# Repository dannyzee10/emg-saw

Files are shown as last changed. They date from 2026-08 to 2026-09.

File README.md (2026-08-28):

# EMG-SAW — Beihang EMG Acquisition System + GUI

An open, low-cost, **5-channel dry-electrode surface-EMG** acquisition system with a
real-time, research-grade GUI — a self-owned alternative to Noraxon MR / Delsys Trigno.
Built and run as a **SAFe Agentic Workflow (SAW)**: 6 specialist agents, a code
knowledge-graph, and an agent "world-map".

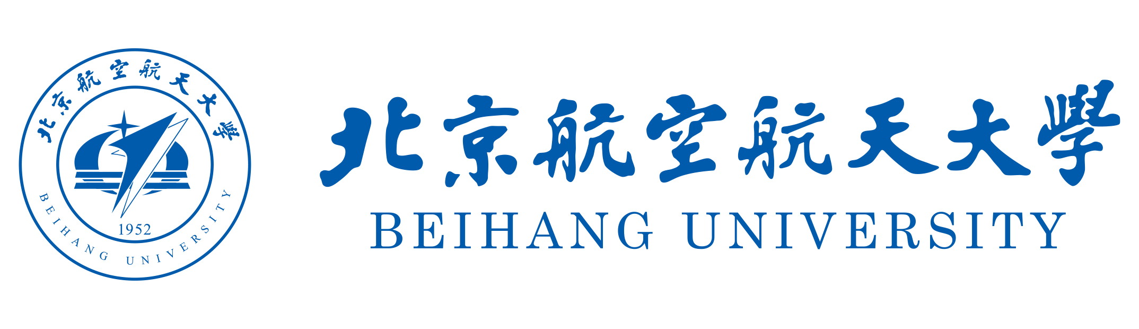
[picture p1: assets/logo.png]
Beihang University


## Quick start
```bash
python -m venv venv
# Windows:  .\venv\Scripts\activate      # macOS/Linux:  source venv/bin/activate
pip install -r requirements.txt

# see the full UI with no hardware:
python emgscope.py --sim --channels 5

# real hardware (STM32 flashed with CP4 firmware, CP2102 on COMx):
python emgscope.py --port COM8 --baud 921600 --channels 1 --fs 2000 --coupling AC --kick
```

## What it does
Real-time multi-channel scope (sweep/scroll, DC/AC/GND coupling, V/div, Time/div) with
per-channel **RMS, pk-pk, median frequency (fatigue), activation meter**, **MVC % normalization**,
**onset highlight**, **live FFT spectrum**, event markers, snapshot, and one-click HTML reports.
Firmware: STM32F103 timer-paced ADC + DMA ping-pong streaming binary frames @ 2 kHz.

## Architecture
```
skin → dry electrodes → analog front-end → STM32 ADC (TIM+DMA) → binary/UART → PC GUI (PyQt5/pyqtgraph)
```

## Repo
- `emgscope.py` — launch the scope · `gui/` (MVC) · `dsp/` · `communication/` · `firmware/`
- `scripts/` — `flash_run.bat`, `refresh.ps1`, `agent_map.py` (world-map)
- **New here? Read [`HANDOFF.md`](HANDOFF.md) first** — complete context, run guide, and roadmap.
- Facts: [`PROJECT_CONTEXT.md`](PROJECT_CONTEXT.md) · Gates: [`QUALITY_BAR.md`](QUALITY_BAR.md) ·
  Roadmap: [`docs/EMG_SAW_Retro_and_Competitive_Roadmap.md`](docs/EMG_SAW_Retro_and_Competitive_Roadmap.md)

## Status
CP1–CP4 complete (2 kHz binary pipeline, full instrument). Next: 5 channels, then ADS1299 24-bit
front-end, wireless, IMU. See `HANDOFF.md` §6–7.

_Owner: Muhammad Daniyal · MS Biomedical Engineering · Beihang University._

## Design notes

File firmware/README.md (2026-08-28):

# EMG Firmware

## Status
Skeleton only. Not yet complete.

## Build Tools
- STM32CubeMX + Keil/IAR/SW4STM32
  or
- PlatformIO (with stm32duino or HAL)

## Configuration
- MCU: STM32F103C8T6 (Blue Pill)
- Clock: 72 MHz (from 8 MHz HSE via PLL)
- ADC: ADC1, 12-bit, 8 channels, DMA circular
- Timer: TIM2, update event @ 2 kHz (period = 72MHz/(2kHz) = 36000, PSC = 0)
- UART: USART1, 921600 baud

## Protocol
- Version: 2
- Frame: 0xAA 0x56 | seq(2) | data(8*2) | crc(2)
- CRC: CRC-16/CCITT-FALSE (poly 0x1021, init 0xFFFF) over seq+data

## TODO
- [ ] Complete HAL initialization code
- [ ] Verify DMA circular buffer size and interrupt priorities
- [ ] Test with PC-side round-trip test
- [ ] Implement hardware flow control if needed

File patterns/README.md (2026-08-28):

# Patterns

> **Note**: This repository already has a `patterns_library/` directory with 11 production patterns.
> This `patterns/` directory is reserved for whitepaper-specific pattern documentation.

## Existing Patterns

See [`../patterns_library/`](../patterns_library/) for:

- 11 production-tested patterns (API, Database, UI)
- Pattern discovery protocol
- Security validation checklists

## Whitepaper Patterns (Coming in v1.1)

Additional patterns documented in the whitepaper will be added here:

- Case study patterns (PGM-321, PGM-323)
- Meta-circular validation patterns
- Evidence-based delivery patterns

## Current Status

For now, see:

- [Existing Pattern Library](../patterns_library/README.md) - 11 production patterns

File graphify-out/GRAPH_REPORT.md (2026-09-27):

# Graph Report - pcb-routing-0925  (2026-09-27)

## Corpus Check
- 942 files · ~5,435,691 words
- Verdict: corpus is large enough that graph structure adds value.

## Summary
- 6135 nodes · 11253 edges · 675 communities (364 shown, 133 thin omitted)
- Extraction: 99% EXTRACTED · 1% INFERRED · 0% AMBIGUOUS · INFERRED: 111 edges (avg confidence: 0.86)
- Token cost: 0 input · 0 output

## Graph Freshness
- Built from commit: `39b95e40`
- Run `git rev-parse HEAD` and compare to check if the graph is stale.
- Run `graphify update .` after code changes (no API cost).

## Community Hubs (Navigation)
- EmgScope
- EMG Bring-up Checkpoint Log
- ReviewWindow
- emg_plotter.py
- graphify query
- emg_bluepill/main.c
- afx_124242.pas
- Beihang University Logo (logo.png)
- graphify clone (GitHub)
- Patterns Library (11 production patterns)
- Token reduction benchmark
- FalkorDB export
- GraphML export
- Neo4j export
- SVG export
- Wiki export
- MVC Normalization (% MVC)
- MetricsCalculator
- Hard gate rules
- EMG SAW — HANDOFF (read this first)
- agent_map.py
- pre-commit
- DSP Engineer Playbook
- Firmware Engineer Playbook
- GUI Engineer Playbook
- Hardware Engineer Playbook
- Test Engineer Playbook
- Systems Architect Playbook (Brain Agent)
- EMG UART Protocol Specification
- Sequence Number Width Evaluation
- EMG Firmware
- src/main.c
- FrameParser
- GUI Architecture Proposal (EMG Instrument)
- EmgPlotWidget
- RecordingController
- test_dsp_analytics.py
- MvcDialog
- Cited Findings
- s3_000002.pas
- AmpNormDialog
- ar2_113622.pas
- Tomorrow — Live PA0 EMG data check (CP5 "signal sanity")
- Cited Findings
- svc_swap3_T.pas
- sc_234902.pas
- a6a_133022.pas
- apq_123711.pas
- svc_swap2_T.pas
- Handler
- sx_233624.pas
- router4.py
- compact_mainboard_20260925T115919Z/work/router5.py
- Lead-off calibration & validation — 2026-08-29
- Launcher
- launchers.md
- Data Pipeline — 5-Channel Simultaneous EMG Streaming (feasibility + optimal design)
- Complete Pin-by-Pin Connection Reference — AS BUILT
- 5-Channel Wireless Wearable EMG Board — Project Handoff
- PROJECT_CONTEXT.md
- Main Board — PCB Layout Rules (floorplan, stack-up, keep-outs, guard, vias)
- Main Board — Power Tree, Schematic-Level Design
- Main Board — 5-Channel Schematic (net-by-net) + BOM
- AFE Signal Chain — confirmed topology + values + 5-channel integration
- QUALITY_BAR.md
- EMG SAW — Retrospective + Competitive Roadmap
- EMG-SAW — Beihang EMG Acquisition System + GUI
- pcb_layout_2026-09-24_routing/work/router5.py
- Analog front-end PCB layout and routing requirements: AD8237 / MCP6404 / MCP6401 / VREF distribution / ADC-input RC / Hirose BK13C (5-ch sEMG main board)
- Fabrication & stack-up limits for the 4-layer JLCPCB EMG main board (80 × 45 mm, FR-4, ENIG, through vias)
- STM32U575VIT6 (LQFP100, non-SMPS): ST layout and routing requirements for U_MCU1 on the EMG main board
- ST67W611M1A6BTR (integrated PCB antenna) on the EMG main board: manufacturer layout requirements for the antenna, grounding, decoupling, 32.768 kHz crystal and SPI host interface
- grid_router.py
- router3.py
- EMG main-board PCB implementation brief — Astra
- compact_mainboard_20260925T115919Z/work/geom.py
- pcb_layout_2026-09-24_routing/work/geom.py
- compact_mainboard_20260925T115919Z/work/apply_ops_v6.pas
- tn_215701.pas
- tr_215530.pas
- ap_171624.pas
- pcb_layout_2026-09-24_routing/work/apply_ops_v6.pas
- aB_213758.pas
- apply_B.pas
- dB_212322.pas
- dC_213555.pas
- fx_214355.pas
- ab2_201729.pas
- ab3_203355.pas
- apply_ops_b2.pas
- apply_ops_b3.pas
- apply_ops_b4.pas
- apply_ops_b5.pas
- apply_ops.pas
- dA_212014.pas
- apply_ops_b1.pas
- EMG main-board placement checkpoint — 24 September 2026
- Unbroken Planes and Tight Loops Govern Routing
- Compact two-sided main board — change audit (R2)
- plan_gnd_fanout2.py
- Remote battery NTC assembly — PROTO_1_REMOTE_NTC
- plan_gnd_fanout.py
- api_test.pas
- at_210845.pas
- Next-agent checkpoint — compact main board (R2)
- apply_fp.pas
- fpB_214118.pas
- fpd_214035.pas
- gen_evidence.py
- compact_mainboard_20260925T115919Z/work/export_geometry.pas
- flip_test.pas
- ft_210529.pas
- gen_B_ops.py
- ot_211603.pas
- outline_test.pas
- Opus continuation changelog — routing revision
- pcb_layout_2026-09-24_routing/work/export_geometry.pas
- plan_bk13_escape.py
- classify_copper.py
- plan_B.py
- compact_mainboard_20260925T115919Z/work/render_area.py
- render_compare.py
- partial_status.py
- peak_mem.py
- probe_board.pas
- pcb_layout_2026-09-24_routing/work/render_area.py
- save_board.pas
- to_local
- compact_mainboard_20260925T115919Z/work/audit_plan.py
- compact_mainboard_20260925T115919Z/work/build_ops.py
- compare_pads.py
- h
- export_baseline.pas
- repair_guided_fix.py
- flip_probe2.pas
- fp_210726.pas
- router_command
- xb_205224.pas
- pcb_layout_2026-09-24_routing/work/audit_plan.py
- pcb_layout_2026-09-24_routing/work/build_ops.py
- probe_bodies.pas
- probe_free_bodies.pas
- replan_pads.py
- route_quality.py
- split_plan.py
- analyze_baseline.py
- analyze_flip.py
- compare_readback.py
- list_sheet.py
- make_trial_ops.py
- compact_mainboard_20260925T115919Z/work/parse_drc.py
- render_placement.py
- repoint_prjpcb.py
- setup_kit.py
- summarize_bodies.py
- build_batch2.py
- build_rule_ops.py
- clean_partial.py
- make_router5.py
- make_writer_test.py
- pcb_layout_2026-09-24_routing/work/parse_drc.py
- render_plan.py
- render_zoom.py
- sy_234341.pas
- dsp.py
- EmgFilters
- ac_235440.pas
- ad_235603.pas
- af_001001.pas
- ag_001433.pas
- apply_C2_T.pas
- as_000004.pas
- plan_C2.py
- ape_052111.pas
- router_command
- routed_plans
- c2lib.py
- emg_features.py
- c2audit.py
- ae_101824.pas
- Compact candidate C2 — change audit (26 Sep 2026)
- find_spot
- place
- export_geometry_T.pas
- gw_001620.pas
- gx_235734.pas
- gy_000106.pas
- gz_001139.pas
- la_233408.pas
- probe_libadd_T.pas
- render_c2_native.py
- lr_233251.pas
- exists
- probe_libread_T.pas
- exists
- routed_plans
- preserved
- export_bodies_T.pas
- make_apply_c2.py
- make_svc_swap3.py
- pr_235306.pas
- probe_pasterule_T.pas
- variant_svc_T.pas
- vs_001533.pas
- vt_001542.pas
- drc_details.py
- gen_c2_svc_ops.py
- make_c2_templates.py
- mkrun.py
- mkvariant.py
- render_service_map.py
- apply_ops_T.pas
- at_105742.pas
- ho_103856.pas
- tc_110641.pas
- tk_110924.pas
- tq_111343.pas
- tr_110331.pas
- tu_111542.pas
- p6c_123528.pas
- gr3_113947.pas
- compare_drc_rounds.py
- g2_by_connection.py
- gd_110815.pas
- ge_111110.pas
- gf_111511.pas
- gh_104401.pas
- gr_111721.pas
- gt_105859.pas
- prune_from_antennae.py
- find_dangling.py
- patch_tools_c2.py
- filter_trial_plan.py
- gen_c2_escape_rules.py
- gen_trial_cleanup_ops.py
- make_c2_round_input.py
- make_c2_trial_input.py
- make_ops_template.py
- plan_to_ops.py
- trial_failures.py
- trial_summary.py
- p6p_123322.pas
- a6o_213811.pas
- a6b_155432.pas
- stitch.py
- a6c_163445.pas
- s6c_123459.pas
- s6d_120322.pas
- s6e_121023.pas
- s6f_122250.pas
- s6g_123036.pas
- stack6_T.pas
- plan_bk13_escape_c2.py
- g6_123554.pas
- g6a_133240.pas
- dru_123247.pas
- dump_rules_T.pas
- rip_conflicts.py
- make_router_input_6l.py
- nudge_stitch.py
- unrouted_summary.py
- ddl_155255.pas
- kop_154628.pas
- p6c2_155904.pas
- p6e_163638.pas
- md2_155729.pas
- mdl_155321.pas
- gaf_052111.pas
- a6g_171008.pas
- relocate_drl.py
- g6b_155350.pas
- g6c_155819.pas
- g6d_155951.pas
- g6e_163611.pas
- g6f_163746.pas
- render_bk13_band.py
- a6h_181848.pas
- a6j_190538.pas
- a6m_193630.pas
- p6h_182535.pas
- p6k_191112.pas
- rgp_194117.pas
- rin_190641.pas
- apr_202815.pas
- C2 6-layer routing completion — resume note (keep this file current)
- g6g_171149.pas
- g6h_182354.pas
- g6i_182649.pas
- g6j_190611.pas
- g6k_191049.pas
- g6l_191206.pas
- g6m2_194006.pas
- g6m_193659.pas
- ggp_195007.pas
- diag_route.py
- mcu_through_traffic.py
- render_routed.py
- rip_blockers.py
- rip_region.py
- apply_rip_offline.py
- repair.py
- a6p_220109.pas
- g6n_202946.pas
- a6q_221928.pas
- mch_220109.pas
- a6s_232727.pas
- a6r_225457.pas
- place_part.py
- g6o_214442.pas
- g6p_220109.pas
- g6q_221928.pas
- render_parts.py
- a6t_001212.pas
- g6r_225457.pas
- ConsistentRepairTests
- a6u_004421.pas
- g6s_232727.pas
- g6t_001212.pas
- a6v_012437.pas
- g6u_004421.pas
- apx_033252.pas
- g6v_012438.pas
- prx_033722.pas
- pry_033832.pas
- rrg_024216.pas
- mrg_024217.pas
- apa_040850.pas
- g6w_024217.pas
- g6x_033252.pas
- g6y_033722.pas
- g6z_033832.pas
- render_window.py
- apc_044145.pas
- pra_041418.pas
- aph_063917.pas
- gaa_040850.pas
- gab_041418.pas
- gac_044145.pas
- plane_route.py
- run_repair.py
- rpg_055739.pas
- mvg_055739.pas
- asw_124433.pas
- mcb_123711.pas
- gloss.py
- gag_055739.pas
- gah_063917.pas
- rip_attached.py
- api_073926.pas
- apn_105426.pas
- rtp_095144.pas
- gai_073926.pas
- apj_083031.pas
- apl_094611.pas
- prj_083356.pas
- gaj_083031.pas
- gak_083357.pas
- gal_094611.pas
- mtp_095144.pas
- gam_095144.pas
- gan_105426.pas
- gao_123712.pas
- gap_124242.pas
- gaq_124433.pas
- fab_check.py
- aup_135846.pas
- rcb_135636.pas
- rrn_125439.pas
- apw_151610.pas
- mcbt_135637.pas
- mr2_125917.pas
- mrn_125439.pas
- gav_151610.pas
- ProcessingDialog
- msk_161919.pas
- gar_125439.pas
- gas_125917.pas
- gat_135637.pas
- gau_135846.pas
- pinswap_T.pas
- psw_161601.pas
- psw_161614.pas
- gaw_161651.pas
- gax_161919.pas
- sch_dump_T.pas
- sdm_155058.pas
- apu_163913.pas
- apz_173925.pas
- Handoff to Astra — C2 6-layer EMG main board: finish the routing (27 Sep 2026, 21:xx)
- uartswap_T.pas
- router_command
- gaz_173925.pas
- merge_rounds.py
- prune_chain.py
- gay_163913.pas
- sdm2_162742.pas
- neg_sweep.py
- astra_verify_routing_delta.py
- .check
- astra_verify_via_rule_delta.py
- astra_apba_185646.pas
- astra_apbb_191935.pas
- astra_apbc_200754.pas
- astra_apbd_202424.pas
- astra_apbe_204152.pas
- astra_apbe_ready_205633.pas
- astra_apbf_final_211832.pas
- astra_apbf_ready_211056.pas
- astra_apbg_220654.pas
- astra_apbg_final_222332.pas
- astra_apbg_rebased_223912.pas
- astra_apbh_225024.pas
- astra_apbh_centered_225113.pas
- astra_apbj_230930.pas
- drc
- GlossContactTests
- astra_audit_trace_rules.py
- NativeTraceRuleTests
- inventory
- explicit_seed
- ASTRA_BF_CS_BOTTOM_PLANNING_ONLY/MANIFEST.json
- ASTRA_BF_CS_SEEDED_PLANNING_ONLY/MANIFEST.json
- ASTRA_BF_TX_SEEDED_PLANNING_ONLY/MANIFEST.json
- astra_verify_pcb_structure.py
- ASTRA_CH4_LOCAL2_PLANNING_ONLY/MANIFEST.json
- astra_align_via_rule_T.pas
- astra_viabi_225318.pas
- All free trace audit and via evidence — 2026-09-27
- Channel 4 routing correction — native checkpoint BC
- Routing completion and all-trace check — BJ, 27 September 2026
- SeedPlansTests
- BF testpad relocation and MCU92 escape: planning evidence
- All-trace verification coverage review
- Gloss contact guard: code and synthetic test evidence, 27 September 2026
- Guided partial-rip corridor and seed plan inputs, 27 September 2026
- MCU UART RX routed — native checkpoint BF
- Radio UART RX routed — native checkpoint BE
- Vc_1 native routing checkpoint BD — 27 September 2026
- astra_gaz_185646.pas
- astra_gba_185646.pas
- astra_gbb_191935.pas
- astra_gbc_200755.pas
- astra_gbd_202424.pas
- astra_gbe_204152.pas
- astra_gbf_210912.pas
- astra_gbfs_223242.pas
- astra_gbg_220655.pas
- astra_gbgm_224135.pas
- astra_gbh_225024.pas
- astra_gbi_225714.pas
- astra_gbj_230930.pas
- astra_move_cl4_T.pas
- astra_mvcl4_200754.pas
- astra_tp_gnd_dig_move_scan.py
- astra_unsavedbf_222959.pas
- Combined bounded cleanup of all ten BH antenna warnings
- astra_ch4_trial.py
- astra_check_mcu_rx_power_graph.py
- astra_check_mcu_rx_reinforced_graph.py
- astra_check_uart_partial_graph.py
- astra_check_uart_rx1_graph.py
- astra_cl4_feasibility.py
- astra_cs_tx_local_detour.py
- astra_finalize_bj.py
- astra_mcu92_inward_seed_check.py
- astra_move_gnd_tp_T.pas
- astra_mvbgm_224135.pas
- MCU_WIFI_UART_RX candidate review
- Two remaining BF opens: independent routing constraints
- astra_check_ch4_candidate.py
- astra_check_vc1_l5_paths.py
- astra_cs_ground_stitch_sites.py
- astra_cs_source_seed_check.py
- astra_final_escape_sites.py
- astra_ina4_rotation_feasibility.py
- astra_scan_ina4_via.py
- astra_tx_final_junction_review.py
- astra_tx_link_seed_check.py
- ASTRA_BC_TRANSLATION_VERIFIER.md
- ASTRA_BD_INDEPENDENT_REVIEW.md
- ASTRA_BE_INDEPENDENT_REVIEW.md
- ASTRA_BF_FINAL_ESCAPE_REVIEW.md
- ASTRA_BF_INDEPENDENT_REVIEW.md
- ASTRA_BG_ANTENNA_BOUNDED_REVIEW.md
- ASTRA_BG_CS_RETURN_REVIEW.md
- ASTRA_BH_BI_RULE_OPTIONS_REVIEW.md
- ASTRA_BH_INDEPENDENT_REVIEW.md
- ASTRA_BJ_INDEPENDENT_REVIEW.md
- ASTRA_FREE_PAD_DELTA_ALLOWANCE.md
- ASTRA_INA4_VIA_SCAN_BB.md
- ASTRA_NETINA4_3_ROUTING_LAYERS_REVIEW.md
- ASTRA_VC1_L5_REVIEW_BC.md
- ASTRA_VC1_NATIVE_RULE_REVIEW_BC.md
- ASTRA_WIFI_UART_RX_NATIVE_RULE_REVIEW_BD.md
- astra_route_seed.py
- clearance_diff.py
- clearance_scan.py

## God Nodes (most connected - your core abstractions)
1. `EmgScope` - 85 edges
2. `router_command` - 38 edges
3. `router_command` - 38 edges
4. `router_command` - 38 edges
5. `ReviewWindow` - 36 edges
6. `routed_plans` - 34 edges
7. `routed_plans` - 34 edges
8. `C2 6-layer routing completion — resume note (keep this file current)` - 34 edges
9. `EmgFilters` - 23 edges
10. `EMG main-board PCB implementation brief — Astra` - 20 edges

## Surprising Connections (you probably didn't know these)
- `Test Engineer (team note)` --semantically_similar_to--> `Test Engineer Agent`  [INFERRED] [semantically similar]
  team/test-engineer.md → .claude/agents/test-engineer.md
- `EMG SAW Agent Roster (agents/)` --semantically_similar_to--> `EMG SAW Agent Roster (docs/)`  [INFERRED] [semantically similar]
  agents/EMG_SAW_Agent_Roster.md → docs/EMG_SAW_Agent_Roster.md
- `DSP Engineer (team note)` --semantically_similar_to--> `DSP Engineer Agent`  [INFERRED] [semantically similar]
  team/dsp-engineer.md → .claude/agents/dsp-engineer.md
- `Firmware Engineer (team note)` --semantically_similar_to--> `Firmware Engineer Agent`  [INFERRED] [semantically similar]
  team/firmware-engineer.md → .claude/agents/firmware-engineer.md
- `GUI Engineer (team note)` --semantically_similar_to--> `GUI Engineer Agent`  [INFERRED] [semantically similar]
  team/gui-engineer.md → .claude/agents/gui-engineer.md

## Import Cycles
- None detected.

## Hyperedges (group relationships)
- **EMG SAW Agent Team** — claude_agents_systems_architect, claude_agents_firmware_engineer, claude_agents_gui_engineer, claude_agents_dsp_engineer, claude_agents_hardware_engineer, claude_agents_test_engineer [EXTRACTED 0.90]
- **CP4 TIM-ADC-DMA Ping-Pong Pipeline** — firmware_cp4_binary_dma_tim3, firmware_bluepill_f103_config_adc1, firmware_bluepill_f103_config_dma, firmware_cp4_binary_dma_hal_adc_convhalfcpltcallback, firmware_cp4_binary_dma_send_half, firmware_stm32_firmware_build_frame [EXTRACTED 0.90]
- **Graphify extra export formats** — _claude_skills_graphify_references_exports_wiki, _claude_skills_graphify_references_exports_neo4j, _claude_skills_graphify_references_exports_falkordb, _claude_skills_graphify_references_exports_svg, _claude_skills_graphify_references_exports_graphml, _claude_skills_graphify_references_exports_mcp [INFERRED 0.85]
- **Extraction schema rules** — _claude_skills_graphify_references_extraction_spec_subagent, _claude_skills_graphify_references_extraction_spec_confidence, _claude_skills_graphify_references_extraction_spec_confidence_score, _claude_skills_graphify_references_extraction_spec_node_id_format, _claude_skills_graphify_references_extraction_spec_semantic_similarity, _claude_skills_graphify_references_extraction_spec_hyperedges [INFERRED 0.85]
- **Query/answer flow** — _claude_skills_graphify_references_query_query, _claude_skills_graphify_references_query_path, _claude_skills_graphify_references_query_explain, _claude_skills_graphify_references_query_expansion, _claude_skills_graphify_references_query_save_result, _claude_skills_graphify_references_query_reflect [INFERRED 0.85]

## Communities (675 total, 133 thin omitted)

### Community 0 - "EmgScope"
Cohesion: 0.05
Nodes (17): EmgScope, Envelope smoothing per the configured Amplitude-Norm algorithm + window. `base`…, Absolute volts in -> displayed volts out (coupling + optional filters)., #9 Save Data step after a test recording: name it (Save & View / Save /…, Open a saved recording in the View/Review window (playback + Operations +…, Rename the just-saved CSV to include the user's name (keeps the emg_ prefix +…, Quick numeric 'view' of a saved recording (per-channel RMS / pk-pk / lead-off)., Guide the Record -> Pause -> Stop activity with a contextual step hint. (+9 more)

### Community 1 - "EMG Bring-up Checkpoint Log"
Cohesion: 0.06
Nodes (64): Graphify Trigger Config (.claude/CLAUDE.md), EMG SAW Agent Roster (agents/), Round Table Collaboration, SAFe Methodology (Epic/Feature/Story), Graphify Project Instructions (CLAUDE.md), DSP Engineer Agent, Firmware Engineer Agent, GUI Engineer Agent (+56 more)

### Community 2 - "ReviewWindow"
Cohesion: 0.08
Nodes (14): NormalizeDialog, NormalizeDialog — Noraxon MR offline Amplitude Normalization config: choose the…, Run the Signal-Processing pipeline per channel; build display array + per-…, Open the Signal Processing pipeline builder; apply the result to the review., Populate self.mvc from the latest mvc_store.json entry (the persisted 'MVC…, Compute a per-channel reference (=100 %) from the chosen source/window, then…, Img15: % axis at the chosen range, a 100 % reference line, and the green 'peak…, ReviewWindow (+6 more)

### Community 3 - "emg_plotter.py"
Cohesion: 0.06
Nodes (25): AsciiSource, _BufferedSource, _open_serial(), ndarray, Data sources for the plotter. Every source runs a background thread that fills…, Fallback for a quick STM32 `printf("%d,%d\\n", ...)` bring-up., Synthetic sEMG: baseline noise + intermittent bursts (band-limited noise…, Open the serial port exactly like a plain read that is known to work here. Open… (+17 more)

### Community 4 - "graphify query"
Cohesion: 0.09
Nodes (24): graphify add (URL ingest), Watch debounce, graphify --watch folder watcher, MCP server, Confidence tiers (EXTRACTED/INFERRED/AMBIGUOUS), Confidence score rubric, Hyperedges, Node ID format (+16 more)

### Community 5 - "emg_bluepill/main.c"
Cohesion: 0.25
Nodes (14): build_frame(), ADC_HandleTypeDef, crc16_ccitt(), Error_Handler(), HAL_ADC_ConvCpltCallback(), HAL_ADC_ConvHalfCpltCallback(), main(), MX_ADC1_Init() (+6 more)

### Community 6 - "afx_124242.pas"
Cohesion: 0.26
Nodes (21): AddCutout(), AddPoly(), CloseTo(), CountItems(), CountPolys(), Counts(), Fail(), FindNet() (+13 more)

### Community 7 - "Beihang University Logo (logo.png)"
Cohesion: 1.00
Nodes (3): Beihang University Logo (logo.png), Beihang University Logo (R.png), Beihang-branded UI Header

### Community 18 - "Hard gate rules"
Cohesion: 0.18
Nodes (11): Hard gate rules, HG10 — No "done" without Daniyal approval, HG1 — Protocol integrity, HG2 — Firmware timing & delivery, HG3 — DSP correctness, HG4 — GUI robustness, HG5 — Axes & display fidelity, HG6 — Signal quality baseline (+3 more)

### Community 19 - "EMG SAW — HANDOFF (read this first)"
Cohesion: 0.15
Nodes (13): 0. How to use this handoff, 10. Push to GitHub (for your coworker), 11. Doc index, 1. Mission, 2. Quick start — open the EMG scope, 3. Current state — DONE ✅ (as of 2026-08-27), 4. Repo map, 5. What each agent did (retro) — the memory of the build (+5 more)

### Community 20 - "agent_map.py"
Cohesion: 0.83
Nodes (3): load_ownership(), main(), owner_of()

### Community 25 - "DSP Engineer Playbook"
Cohesion: 0.25
Nodes (7): Common Pitfalls, DSP Engineer Playbook, Exit State, Knowledge Base, Quality Gates, Role, Workflow

### Community 26 - "Firmware Engineer Playbook"
Cohesion: 0.25
Nodes (7): Common Pitfalls, Exit State, Firmware Engineer Playbook, Knowledge Base, Quality Gates, Role, Workflow

### Community 27 - "GUI Engineer Playbook"
Cohesion: 0.25
Nodes (7): Common Pitfalls, Exit State, GUI Engineer Playbook, Knowledge Base, Quality Gates, Role, Workflow

### Community 28 - "Hardware Engineer Playbook"
Cohesion: 0.25
Nodes (7): Common Pitfalls, Exit State, Hardware Engineer Playbook, Knowledge Base, Quality Gates, Role, Workflow

### Community 29 - "Test Engineer Playbook"
Cohesion: 0.25
Nodes (7): Common Pitfalls, Exit State, Knowledge Base, Quality Gates, Role, Test Engineer Playbook, Workflow

### Community 30 - "Systems Architect Playbook (Brain Agent)"
Cohesion: 0.29
Nodes (6): Core Workflow (Task Delegation), Quality Gates, Role, Stop-the-Line Rules, Systems Architect Playbook (Brain Agent), Token Discipline

### Community 31 - "EMG UART Protocol Specification"
Cohesion: 0.07
Nodes (29): Channel Data Format, Channel Data Format, CRC Algorithm, CRC Algorithm, EMG UART Protocol Specification, EMG UART Protocol Specification, Error Handling, Error Handling (+21 more)

### Community 32 - "Sequence Number Width Evaluation"
Cohesion: 0.22
Nodes (8): Action Items, Calculation, Context, Date, Impact, Recommendation, Sequence Number Width Evaluation, Status

### Community 33 - "EMG Firmware"
Cohesion: 0.29
Nodes (6): Build Tools, Configuration, EMG Firmware, Protocol, Status, TODO

### Community 34 - "src/main.c"
Cohesion: 0.47
Nodes (4): ADC_HandleTypeDef, crc16_ccitt(), HAL_ADC_ConvCpltCallback(), send_frame()

### Community 35 - "FrameParser"
Cohesion: 0.15
Nodes (18): crc16_ccitt(), encode_frame(), FrameParser, Wire protocol shared by the STM32 firmware and the laptop plotter. Version 1…, CRC-16/CCITT-FALSE (poly 0x1021, init 0xFFFF). Matches the C code in firmware/., Build one frame. `version` = 1 for legacy 8-bit seq, 2 for 16-bit seq., Streaming parser that auto-detects protocol version per frame. Yields (seq,…, main() (+10 more)

### Community 36 - "GUI Architecture Proposal (EMG Instrument)"
Cohesion: 0.22
Nodes (8): Controller, Current State, Data Flow, GUI Architecture Proposal (EMG Instrument), Immediate Refactoring Steps, Model, Proposed Modular Architecture, View

### Community 37 - "EmgPlotWidget"
Cohesion: 0.14
Nodes (6): EmgPlotWidget, Holds the GraphicsLayoutWidget, per-channel plots, curves, overlays, cursors,…, Show/hide the spectrum plot., Update all channel curves with new data. `data` shape (n_samples, nch)., Update onset overlay for channel c., Update spectrum curves. `psd_list` is list of arrays per channel.

### Community 38 - "RecordingController"
Cohesion: 0.17
Nodes (6): RecordingController – manages CSV recording independent of the GUI., Open a new CSV file and write metadata header., Write a chunk of raw samples to the file. `new_data` shape (n_samples, nch)., Write a marker line (preceded by #) to the file., Handles opening, writing, and closing a CSV file for raw EMG data., RecordingController

### Community 39 - "test_dsp_analytics.py"
Cohesion: 0.10
Nodes (29): cocontraction_index(), fatigue_trend(), iemg(), mean_frequency(), median_frequency(), onset_offset(), Integrated EMG (iEMG): area under the full-wave-rectified signal, ∫|EMG| dt…, Mean power-frequency MNF (Hz): the spectral centroid MNF = Σ f·P(f) / Σ P(f)… (+21 more)

### Community 40 - "MvcDialog"
Cohesion: 0.09
Nodes (15): MvcDialog, MvcSaveDialog, MvcDialog — Noraxon-style MVC calibration with guided steps. Open → live RMS-…, Noraxon-style 'Save Data' step shown right after an MVC capture: name the…, Noraxon-style 'Save Data' shown after stopping a test recording: name the…, SaveRecordingDialog, _style(), _chunk() (+7 more)

### Community 41 - "Cited Findings"
Cohesion: 0.06
Nodes (33): 1. BQ24072T (UP1): IN/OUT/BAT capacitor placement, high-current paths, exposed-pad vias and via-in-pad treatment, ISET/ILIM/TMR/TS placement and quiet ground, thermal guidance, 2. GCT USB4105-GF-A (J_USB_C): which pins carry VBUS/GND, shell and stake grounding, copper/vias for the charger input current, keep-outs, 3. ESD protection layout (D_VBUS = Nexperia PESD5V0S1BA,115 SOD-323; D_CC_ESD = Nexperia PESD5V0X2UTR SOT-23), 4. MAX17048 (UP4): CELL/VDD sensing (Kelvin at the battery terminal, avoiding charge-current IR drop), VDD bypass, exposed pad, I2C pull-ups, 5. TS/NTC sensing: routing the remote 103AT-2 leads and noise on TS, Charger / USB-C input / ESD / fuel gauge / battery-NTC: PCB routing requirements (UP1 BQ24072T, J_USB_C USB4105-GF-A, D_VBUS PESD5V0S1BA, D_CC_ESD PESD5V0X2UT, UP4 MAX17048, R_TH_BAT 103AT-2), Cited Findings, Cited Findings (+25 more)

### Community 42 - "s3_000002.pas"
Cohesion: 0.21
Nodes (25): AddLibToProject(), AddNpth(), AddSmd(), AssignNets(), BuildLibrary(), CopyFootprint(), CountPads(), FindComp() (+17 more)

### Community 43 - "AmpNormDialog"
Cohesion: 0.14
Nodes (9): AmpNormDialog, AmpNormDialog — Noraxon MR real-time Amplitude Normalization + Smoothing…, Headless GUI smoke test (HG4): build the branded MVC instrument at 5 channels,…, HG4: the HTML report builds (with the M3 analytics columns) without exception., Img1/Img3/Img4: the live envelope honors the smoothing algorithm + window, and…, test_amp_norm_dialog_reports_config(), test_gui_builds_and_runs_5ch(), test_live_smoothing_algorithms_and_pipeline() (+1 more)

### Community 44 - "ar2_113622.pas"
Cohesion: 0.29
Nodes (19): AddCutout(), AddPoly(), CloseTo(), CountItems(), Counts(), Fail(), FindNet(), FindRule() (+11 more)

### Community 45 - "Tomorrow — Live PA0 EMG data check (CP5 "signal sanity")"
Cohesion: 0.17
Nodes (11): 0. Pre-flight (2 min), 1. Stream, 2. Resting baseline / noise (muscle relaxed), 3. DC / scale sanity (CP5), 4. Contraction / activation — the real test, 5. Fatigue (optional), 6. Capture the data, After the session (+3 more)

### Community 46 - "Cited Findings"
Cohesion: 0.06
Nodes (33): 1. TPS631000 layout guidelines, layout example and EVM: critical loops, CIN/COUT/inductor placement, LX copper, GND vias, FB and feed-forward placement, thermal copper, vias under the IC, 2. Peak inductor/switch currents at 3.3 V / 0.6 A from 3.0–4.2 V, and the resulting trace widths and via counts (1 oz outer, 0.5 oz inner), 3. TPS7A2030 (UP3) layout: capacitor placement, ground return, PSRR when fed from the switching 3V3_DIG rail, distributing 3V0_ANA to the analog bank, 4. TPS3808G33 (U_UV1, CT open) and LTC2954-1 (U_EN1): layout notes, timing pins, pull-ups, noise susceptibility, keep-away from switch nodes, 5. Separating the switching converter from sensitive analog: minimum distances, what must not run under the inductor or switch node, and whether L2 must stay unbroken under the switcher, Cited Findings, Cited Findings, Cited Findings (+25 more)

### Community 47 - "svc_swap3_T.pas"
Cohesion: 0.21
Nodes (25): AddLibToProject(), AddNpth(), AddSmd(), AssignNets(), BuildLibrary(), CopyFootprint(), CountPads(), FindComp() (+17 more)

### Community 48 - "sc_234902.pas"
Cohesion: 0.22
Nodes (24): AddLibToProject(), AddNpth(), AddSmd(), AssignNets(), BuildLibrary(), CopyFootprint(), CountPads(), FindComp() (+16 more)

### Community 49 - "a6a_133022.pas"
Cohesion: 0.26
Nodes (21): AddCutout(), AddPoly(), CloseTo(), CountItems(), CountPolys(), Counts(), Fail(), FindNet() (+13 more)

### Community 50 - "apq_123711.pas"
Cohesion: 0.26
Nodes (21): AddCutout(), AddPoly(), CloseTo(), CountItems(), CountPolys(), Counts(), Fail(), FindNet() (+13 more)

### Community 51 - "svc_swap2_T.pas"
Cohesion: 0.22
Nodes (24): AddLibToProject(), AddNpth(), AddSmd(), AssignNets(), BuildLibrary(), CopyFootprint(), CountPads(), FindComp() (+16 more)

### Community 53 - "sx_233624.pas"
Cohesion: 0.08
Nodes (58): layer, AddLibToProject(), AddNpth(), AddSmd(), BuildLibrary(), FindComp(), FindNet(), Line() (+50 more)

### Community 54 - "router4.py"
Cohesion: 0.11
Nodes (29): Render router4's view of one unrouted connection: free cells per layer, entry…, Plan the pour stage (offline; Altium DRC is the authority). Emits…, allowed_layers(), astar(), cell_xy(), cls(), edt(), end_copper() (+21 more)

### Community 55 - "compact_mainboard_20260925T115919Z/work/router5.py"
Cohesion: 0.11
Nodes (35): allowed_layers(), astar(), _astar_pen(), cell_xy(), cls(), comp_nodes(), component(), edt() (+27 more)

### Community 56 - "Lead-off calibration & validation — 2026-08-29"
Cohesion: 0.40
Nodes (4): Calibrated thresholds (`dsp.leadoff_report`), Findings, Lead-off calibration & validation — 2026-08-29, Notes

### Community 59 - "Data Pipeline — 5-Channel Simultaneous EMG Streaming (feasibility + optimal design)"
Cohesion: 0.22
Nodes (8): 1. The data rate is tiny, 2. "All 5 at the same time" is easy on the U575, 3. What actually makes it "work well" (the 4 keys), 4. Better option? Wi-Fi vs BLE vs USB, 5. The one honest risk + the fix, 6. Recommended optimal config, 7. This is exactly what the dev-board step (Step 3) proves, Data Pipeline — 5-Channel Simultaneous EMG Streaming (feasibility + optimal design)

### Community 60 - "Complete Pin-by-Pin Connection Reference — AS BUILT"
Cohesion: 0.15
Nodes (12): 10. FFC to each electrode board (13-pin, GND-interleaved), 11. Still to do on the schematic, 1. J1 — USB4105-GF-A-060 (USB-C receptacle, 16 contacts + 8 dummy), 2. UP1 — MCP73831T-2ACI/MC (Li-Po charger, **DFN-8** — *not* the SOT-23-5 pinout), 3. J_Li-Po (Header 2) + Q1 — DMP2045U-7 (reverse-polarity, SOT-23 P-MOS), 4. UP3 — TPS2116DRLR (power mux, SOT-583) — USB priority, 5. UP4 — TPS631000DRLR (buck-boost, SOT-583) → 3V3_DIG = 3.30 V, 6. UP5 — TPS7A2030PDBVR (analog LDO, SOT-23-5) → 3V3_ANA = 3.00 V (+4 more)

### Community 61 - "5-Channel Wireless Wearable EMG Board — Project Handoff"
Cohesion: 0.18
Nodes (10): 1. What this board is, 2. Documents in this folder, 3. Architecture decisions (and why), 4. Timeline of what was done, 5-Channel Wireless Wearable EMG Board — Project Handoff, 5. The review that changed the design, 6. Open items before design freeze, 7. Safety position (research device, not certified) (+2 more)

### Community 62 - "PROJECT_CONTEXT.md"
Cohesion: 0.20
Nodes (9): Architecture (locked pipeline), Current state — DONE ✅ (as of 2026-08-26), Locked gotchas (each cost hours — do NOT rediscover), Locked hardware facts, Locked wire protocol, Project identity, Roadmap, Signal facts (+1 more)

### Community 63 - "Main Board — PCB Layout Rules (floorplan, stack-up, keep-outs, guard, vias)"
Cohesion: 0.17
Nodes (11): 10. Layout review checklist (I'll check each snapshot against this), 1. Stack-up — YES, 4-layer (2-layer cannot do Wi-Fi + µV EMG), 2. Floorplan — where everything goes, 3. Placement rules per block, 4. Keep-outs, 5. Ground = ONE solid plane, separation by placement, 6. Guard ring (per channel), 7. Decoupling & vias (+3 more)

### Community 64 - "Main Board — Power Tree, Schematic-Level Design"
Cohesion: 0.18
Nodes (10): 0. Rail decisions — REVISED 2026-09-05, 1. USB-C input + protection, 2. Charger — MCP73831, 3. Battery + reverse-polarity + power-path mux, 4. Buck-boost pre-regulator — TPS631000 → 3V3_DIG (3.5 V), 5. Analog LDO — TPS7A2033 → 3V3_ANA (3.3 V, fixed), 6. Fuel gauge — MAX17048 (on the battery node), 7. Power-section BOM (subtotal) (+2 more)

### Community 65 - "Main Board — 5-Channel Schematic (net-by-net) + BOM"
Cohesion: 0.22
Nodes (8): A. Per-channel AFE  (replicate ×5), B. Shared analog blocks (once for all 5 channels) — **DRL-free, see `02` decision**, C. STM32U575AII6Q  (ADC + host; set exact pins in CubeMX), D. ST67W611M1-B  (Wi-Fi/BLE module; pins per ST datasheet / B2413 ref), E. Connectors, F. Consolidated BOM (main board), G. Verify, Main Board — 5-Channel Schematic (net-by-net) + BOM

### Community 66 - "AFE Signal Chain — confirmed topology + values + 5-channel integration"
Cohesion: 0.29
Nodes (6): AFE Signal Chain — confirmed topology + values + 5-channel integration, Amp count after the change — packs perfectly into 3 quads, DECISION 2026-09-04 — **DRL REMOVED** (grounded reference instead), Open items, Per-channel chain (proven — reuse exactly), Shared blocks on the main board (generate once for all 5 ch)

### Community 67 - "QUALITY_BAR.md"
Cohesion: 0.22
Nodes (3): Authority, Gate reference, Supporting rules (a pattern of violations becomes blocking)

### Community 68 - "EMG SAW — Retrospective + Competitive Roadmap"
Cohesion: 0.22
Nodes (9): EMG SAW — Retrospective + Competitive Roadmap, Next STM32 upgrade — all 15 electrodes (deferred; needs more/faster ADC), Now — Blue Pill, Channel 1, 3 electrodes (no mux, reuses existing software), Part 1 — What each agent shipped (retro of the build), Part 2 — Remaining goals per agent (near-term), Part 3 — Where we stand vs Delsys & Noraxon, Part 4 — The "win" roadmap (prioritized), Part 5 — Electrode lead-off / integrity plan (+1 more)

### Community 69 - "EMG-SAW — Beihang EMG Acquisition System + GUI"
Cohesion: 0.33
Nodes (6): Architecture, EMG-SAW — Beihang EMG Acquisition System + GUI, Quick start, Repo, Status, What it does

### Community 70 - "pcb_layout_2026-09-24_routing/work/router5.py"
Cohesion: 0.13
Nodes (30): allowed_layers(), astar(), cell_xy(), cls(), comp_nodes(), component(), edt(), end_copper() (+22 more)

### Community 71 - "Analog front-end PCB layout and routing requirements: AD8237 / MCP6404 / MCP6401 / VREF distribution / ADC-input RC / Hirose BK13C (5-ch sEMG main board)"
Cohesion: 0.07
Nodes (26): Analog front-end PCB layout and routing requirements: AD8237 / MCP6404 / MCP6401 / VREF distribution / ADC-input RC / Hirose BK13C (5-ch sEMG main board), Cited Findings, Cited Findings, Cited Findings, Cited Findings, Cited Findings, Gaps, Gaps (+18 more)

### Community 72 - "Fabrication & stack-up limits for the 4-layer JLCPCB EMG main board (80 × 45 mm, FR-4, ENIG, through vias)"
Cohesion: 0.07
Nodes (26): Cited Findings, Cited Findings, Cited Findings, Cited Findings, Cited Findings, Fabrication & stack-up limits for the 4-layer JLCPCB EMG main board (80 × 45 mm, FR-4, ENIG, through vias), Gaps, Gaps (+18 more)

### Community 73 - "STM32U575VIT6 (LQFP100, non-SMPS): ST layout and routing requirements for U_MCU1 on the EMG main board"
Cohesion: 0.07
Nodes (26): 1. AN5373 (current revision): decoupling per VDD/VSS pair, VCAP, VDDA/VREF+, VBAT, VDDUSB/VDDIO2, NRST/BOOT0 and the PCB-layout section, 2. DS13737: LQFP100 pinout facts and electrical limits that matter for routing, 3. AN2834 and U5 ADC data: analog input routing, separation from digital, RC at the pin, VREF+ decoupling, ground return, 4. SWD routing and SPI-master routing (series termination, trace length), 5. ST reference hardware: how decoupling and VCAP are actually placed on 4-layer boards, Cited Findings, Cited Findings, Cited Findings (+18 more)

### Community 74 - "ST67W611M1A6BTR (integrated PCB antenna) on the EMG main board: manufacturer layout requirements for the antenna, grounding, decoupling, 32.768 kHz crystal and SPI host interface"
Cohesion: 0.07
Nodes (26): 1. Datasheet, application note and user manual: antenna keep-out, module location, ground plane, ground under the module, GND vias, decoupling, traces under the module, 2. ST wiki "Connectivity:ST67W611M1_Antenna_and_RF" and related ST wiki pages: every layout rule, figure and dimension, and any statement about stitching vias near the antenna, 3. ST reference and evaluation boards using ST67W611M1 (STDES-67W61BU-U5 / B2413; X-NUCLEO-67W61M1 / MB2230): what their layout does around the module, 4. 32.768 kHz crystal layout (Epson FC-135 Q13FC13500003 on ST67 pins 13/14): trace length, guard ring grounding, no signals underneath, parasitic capacitance, 5. SPI host interface: clock frequency used by the ST host stack, series termination, trace length and impedance, return path; UART, BOOT and CHIP_EN notes, Cited Findings, Cited Findings, Cited Findings (+18 more)

### Community 75 - "grid_router.py"
Cohesion: 0.13
Nodes (13): astar(), end_copper(), end_nodes(), main(), maps(), parse_conn(), Rule-aware windowed grid router for the remaining connections (offline planner;…, all copper as (geom, net, layerset, wide, finepad) with a spatial index; new… (+5 more)

### Community 76 - "router3.py"
Cohesion: 0.18
Nodes (22): allowed_layers(), astar(), cell_xy(), cls(), edt(), end_copper(), end_nodes(), layer_cost() (+14 more)

### Community 77 - "EMG main-board PCB implementation brief — Astra"
Cohesion: 0.10
Nodes (20): 10. STM32 and ADC details, 11. ST67, SPI, crystal, and antenna, 12. USB, charger, converter, gauge, and remote NTC, 13. Copper pours, vias, and return paths, 14. Test access and connector serviceability, 15. BK13 mechanical contract, 16. Following routing stage: sequence and checks, 17. Verification and honest acceptance criteria (+12 more)

### Community 78 - "compact_mainboard_20260925T115919Z/work/geom.py"
Cohesion: 0.11
Nodes (17): main(), Small fixed via-site/stub checks for WIFI_UART_RX; no router or CAD writes., base_clr(), hole_gap(), in_zone(), Index, _inside(), load() (+9 more)

### Community 79 - "pcb_layout_2026-09-24_routing/work/geom.py"
Cohesion: 0.14
Nodes (13): base_clr(), in_zone(), Index, _inside(), load(), Obj, pad_poly(), Shared offline geometry/rule model for planning and pre-write verification.… (+5 more)

### Community 80 - "compact_mainboard_20260925T115919Z/work/apply_ops_v6.pas"
Cohesion: 0.29
Nodes (19): AddCutout(), AddPoly(), CloseTo(), CountItems(), Counts(), Fail(), FindNet(), FindRule() (+11 more)

### Community 81 - "tn_215701.pas"
Cohesion: 0.29
Nodes (19): AddCutout(), AddPoly(), CloseTo(), CountItems(), Counts(), Fail(), FindNet(), FindRule() (+11 more)

### Community 82 - "tr_215530.pas"
Cohesion: 0.29
Nodes (19): AddCutout(), AddPoly(), CloseTo(), CountItems(), Counts(), Fail(), FindNet(), FindRule() (+11 more)

### Community 83 - "ap_171624.pas"
Cohesion: 0.29
Nodes (19): AddCutout(), AddPoly(), CloseTo(), CountItems(), Counts(), Fail(), FindNet(), FindRule() (+11 more)

### Community 84 - "pcb_layout_2026-09-24_routing/work/apply_ops_v6.pas"
Cohesion: 0.29
Nodes (19): AddCutout(), AddPoly(), CloseTo(), CountItems(), Counts(), Fail(), FindNet(), FindRule() (+11 more)

### Community 85 - "aB_213758.pas"
Cohesion: 0.23
Nodes (18): CloseTo(), Fail(), FindComp(), FindKeepout(), FindPoly(), FindRule(), FindTrack(), FindVia() (+10 more)

### Community 86 - "apply_B.pas"
Cohesion: 0.23
Nodes (18): CloseTo(), Fail(), FindComp(), FindKeepout(), FindPoly(), FindRule(), FindTrack(), FindVia() (+10 more)

### Community 87 - "dB_212322.pas"
Cohesion: 0.23
Nodes (18): CloseTo(), Fail(), FindComp(), FindKeepout(), FindPoly(), FindRule(), FindTrack(), FindVia() (+10 more)

### Community 88 - "dC_213555.pas"
Cohesion: 0.23
Nodes (18): CloseTo(), Fail(), FindComp(), FindKeepout(), FindPoly(), FindRule(), FindTrack(), FindVia() (+10 more)

### Community 89 - "fx_214355.pas"
Cohesion: 0.23
Nodes (18): CloseTo(), Fail(), FindComp(), FindKeepout(), FindPoly(), FindRule(), FindTrack(), FindVia() (+10 more)

### Community 90 - "ab2_201729.pas"
Cohesion: 0.28
Nodes (18): AddPoly(), CloseTo(), CountItems(), Counts(), Fail(), FindNet(), FindRule(), FindTrack() (+10 more)

### Community 91 - "ab3_203355.pas"
Cohesion: 0.28
Nodes (18): AddPoly(), CloseTo(), CountItems(), Counts(), Fail(), FindNet(), FindRule(), FindTrack() (+10 more)

### Community 92 - "apply_ops_b2.pas"
Cohesion: 0.28
Nodes (18): AddPoly(), CloseTo(), CountItems(), Counts(), Fail(), FindNet(), FindRule(), FindTrack() (+10 more)

### Community 93 - "apply_ops_b3.pas"
Cohesion: 0.28
Nodes (18): AddPoly(), CloseTo(), CountItems(), Counts(), Fail(), FindNet(), FindRule(), FindTrack() (+10 more)

### Community 94 - "apply_ops_b4.pas"
Cohesion: 0.28
Nodes (18): AddPoly(), CloseTo(), CountItems(), Counts(), Fail(), FindNet(), FindRule(), FindTrack() (+10 more)

### Community 95 - "apply_ops_b5.pas"
Cohesion: 0.28
Nodes (18): AddPoly(), CloseTo(), CountItems(), Counts(), Fail(), FindNet(), FindRule(), FindTrack() (+10 more)

### Community 96 - "apply_ops.pas"
Cohesion: 0.32
Nodes (17): AddCutout(), AddPoly(), CloseTo(), CountItems(), Counts(), FindNet(), FindRule(), FindTrack() (+9 more)

### Community 97 - "dA_212014.pas"
Cohesion: 0.26
Nodes (16): CloseTo(), Fail(), FindComp(), FindKeepout(), FindPoly(), FindRule(), FindTrack(), FindVia() (+8 more)

### Community 98 - "apply_ops_b1.pas"
Cohesion: 0.31
Nodes (16): AddPoly(), CloseTo(), CountItems(), Counts(), FindNet(), FindRule(), FindTrack(), Fld() (+8 more)

### Community 99 - "EMG main-board placement checkpoint — 24 September 2026"
Cohesion: 0.13
Nodes (13): Placement checkpoint files, 10. Deliverable status, 11. Native image package — 24 September 2026, 1. Open this working revision, 2. Actual physical-board partition and assembly, 3. Changes and preservation, 4. Verification evidence and its dates, 5. Placement, stack and rule decisions (+5 more)

### Community 100 - "Unbroken Planes and Tight Loops Govern Routing"
Cohesion: 0.15
Nodes (12): A 205× gain makes VREF taps as sensitive as electrode inputs, Charger, USB-C and ESD belong in one connector-edge power zone, Conclusion, Every return path depends on an unbroken L2 and L4, LDO and supervisors, Ordering the wrong JLC stack would shift impedance by 40 %, Six schematic issues that no amount of routing can fix, Stop-the-line checks in review order (+4 more)

### Community 101 - "Compact two-sided main board — change audit (R2)"
Cohesion: 0.17
Nodes (11): 10. Open issues (ranked), 1. Source recovery and protection, 2. Native capability proof (disposable copies only), 3. Baseline A measurement, 4. What changed in candidate B, 5. Verification (saved state), 6. Why not 70 × 40 (limiting objects) — candidate C not attempted, 7. Return-path strategy (R2 §8, option A retained) (+3 more)

### Community 102 - "plan_gnd_fanout2.py"
Cohesion: 0.22
Nodes (6): connected(), near_pad(), GND fanout v2 on the shared rule model (true copper, rule priorities, BK13 plan…, first VALID via position along each of 24 rays (true copper, rule model); best…, pad already reaches a GND via directly or through an existing top GND track., search()

### Community 103 - "Remote battery NTC assembly — PROTO_1_REMOTE_NTC"
Cohesion: 0.22
Nodes (8): Cell attachment and wiring, Electrical and physical arrangement, Installation and charger checks, Open qualification items, Procurement and assembly reconciliation, Remote battery NTC assembly — PROTO_1_REMOTE_NTC, Required sensor and manufacturer limits, Termination and strain relief

### Community 104 - "plan_gnd_fanout.py"
Cohesion: 0.31
Nodes (6): clear(), clr_for(), clr_obs(), connected(), padrect(), Plan GND fanout: one short top-layer stub + 0.6/0.3 via per unconnected top-…

### Community 105 - "api_test.pas"
Cohesion: 0.52
Nodes (6): Corner(), FirstOf(), Line(), MM(), RunFixed(), Say()

### Community 106 - "at_210845.pas"
Cohesion: 0.52
Nodes (6): Corner(), FirstOf(), Line(), MM(), RunFixed(), Say()

### Community 107 - "Next-agent checkpoint — compact main board (R2)"
Cohesion: 0.25
Nodes (7): Completed operations (25 Sep 2026), Next-agent checkpoint — compact main board (R2), Next authorized step (after the user's review), Open this, Tooling (all in `work/`), Update 26 Sep 2026: candidate C2 (59.1 × 36.0 mm) — PLACEMENT CHECKPOINT, Update 26 Sep 2026 (later): C2 4-layer routing trial — 2 rounds, LAYER DECISION PENDING

### Community 108 - "apply_fp.pas"
Cohesion: 0.67
Nodes (5): Fld(), MM(), Num(), RunFixed(), Say()

### Community 109 - "fpB_214118.pas"
Cohesion: 0.67
Nodes (5): Fld(), MM(), Num(), RunFixed(), Say()

### Community 110 - "fpd_214035.pas"
Cohesion: 0.67
Nodes (5): Fld(), MM(), Num(), RunFixed(), Say()

### Community 112 - "compact_mainboard_20260925T115919Z/work/export_geometry.pas"
Cohesion: 0.80
Nodes (4): MM(), NetOf(), RectS(), RunFixed()

### Community 113 - "flip_test.pas"
Cohesion: 0.80
Nodes (4): Dump(), FindC(), MM(), RunFixed()

### Community 114 - "ft_210529.pas"
Cohesion: 0.80
Nodes (4): Dump(), FindC(), MM(), RunFixed()

### Community 115 - "gen_B_ops.py"
Cohesion: 0.40
Nodes (3): gvec(), Generate work/B_OPS.txt for apply_B.pas from the verified plan…, translation vector of a component that stays on its side, else None

### Community 116 - "ot_211603.pas"
Cohesion: 0.80
Nodes (4): MM(), RunFixed(), Say(), SetSeg()

### Community 117 - "outline_test.pas"
Cohesion: 0.80
Nodes (4): MM(), RunFixed(), Say(), SetSeg()

### Community 118 - "Opus continuation changelog — routing revision"
Cohesion: 0.40
Nodes (4): 24 Sep 2026, 25 Sep 2026 (resumed; this copy lives in worktree `.claude/worktrees/pcb-routing-0925`, branch `pcb-routing-0925`), Method, Opus continuation changelog — routing revision

### Community 119 - "pcb_layout_2026-09-24_routing/work/export_geometry.pas"
Cohesion: 0.80
Nodes (4): MM(), NetOf(), RectS(), RunFixed()

### Community 120 - "plan_bk13_escape.py"
Cohesion: 0.40
Nodes (3): pattern(), BK13 (0.35 mm pitch) socket escape pattern, identical for J_FPC1..5. Top row 1…, v2: keepout-clearance-correct (0.13 mm to the between-row keepout), 0.15 mm…

### Community 124 - "render_compare.py"
Cohesion: 0.67
Nodes (3): board(), draw(), Same-scale baseline-vs-candidate renders and an X-ray projection, from saved…

### Community 126 - "peak_mem.py"
Cohesion: 0.67
Nodes (3): peak_mb(), PMC, Run a script via runpy and print the Windows peak working set on exit (no…

### Community 127 - "probe_board.pas"
Cohesion: 0.83
Nodes (3): MM(), NetOf(), RunFixed()

### Community 129 - "save_board.pas"
Cohesion: 1.00
Nodes (3): Counts(), RunFixed(), Say()

### Community 130 - "to_local"
Cohesion: 0.18
Nodes (10): R(), world point of part p (B state) -> part-local coordinates, to_local(), to_world(), Where should each kept thermal via be (owner part transform), and where is it…, C2 fix pass: ops from the SAVED NATIVE state (GEOMETRY_C2_PLACED.txt) to the…, Generate work/C2_OPS.txt for apply_C2.pas from the audited plan (plan_C2.pkl)…, load() (+2 more)

### Community 134 - "h"
Cohesion: 0.17
Nodes (11): h, MM(), RunFixed(), MM(), RunFixed(), MM(), RunFixed(), MM() (+3 more)

### Community 136 - "repair_guided_fix.py"
Cohesion: 0.05
Nodes (63): access_mask(), bk13_groups(), commit_exact(), _dead(), disk(), exact_ok(), _fail(), fixed_path_victims() (+55 more)

### Community 139 - "router_command"
Cohesion: 0.04
Nodes (47): allowed_move, component, delta_x_mm, delta_y_mm, base_sha256, explicit_seeds, initial_deletions, C:\\Users\\PMLS\\AppData\\Local\\Programs\\Python\\Python312\\python.exe (+39 more)

### Community 200 - "sy_234341.pas"
Cohesion: 0.22
Nodes (23): AddLibToProject(), AddNpth(), AddSmd(), AssignNets(), BuildLibrary(), CopyFootprint(), CountPads(), FindComp() (+15 more)

### Community 201 - "dsp.py"
Cohesion: 0.12
Nodes (26): leadoff_report(), leadoff_status(), LeadoffTracker, Display-side signal processing (done on the laptop, so you can tweak live —…, Back-compatible wrapper: just the state string from :func:`leadoff_report`., Per-channel electrode lead-off with temporal hysteresis (no flicker) and a…, Analyse one RAW (un-notched, absolute-volt) single-channel window; return…, load() (+18 more)

### Community 202 - "EmgFilters"
Cohesion: 0.05
Nodes (38): EmgFilters, ndarray, Moving-RMS linear envelope, sqrt(mean(x^2)) over a `win_ms` window — the…, _ac(), apply_pipeline(), compute_reference(), op_mean(), op_norm_mvc() (+30 more)

### Community 203 - "ac_235440.pas"
Cohesion: 0.22
Nodes (19): CloseTo(), Fail(), FindComp(), FindFreePad(), FindKeepout(), FindPoly(), FindRule(), FindTrack() (+11 more)

### Community 204 - "ad_235603.pas"
Cohesion: 0.22
Nodes (19): CloseTo(), Fail(), FindComp(), FindFreePad(), FindKeepout(), FindPoly(), FindRule(), FindTrack() (+11 more)

### Community 205 - "af_001001.pas"
Cohesion: 0.22
Nodes (19): CloseTo(), Fail(), FindComp(), FindFreePad(), FindKeepout(), FindPoly(), FindRule(), FindTrack() (+11 more)

### Community 206 - "ag_001433.pas"
Cohesion: 0.22
Nodes (19): CloseTo(), Fail(), FindComp(), FindFreePad(), FindKeepout(), FindPoly(), FindRule(), FindTrack() (+11 more)

### Community 207 - "apply_C2_T.pas"
Cohesion: 0.22
Nodes (19): CloseTo(), Fail(), FindComp(), FindFreePad(), FindKeepout(), FindPoly(), FindRule(), FindTrack() (+11 more)

### Community 208 - "as_000004.pas"
Cohesion: 0.22
Nodes (19): CloseTo(), Fail(), FindComp(), FindFreePad(), FindKeepout(), FindPoly(), FindRule(), FindTrack() (+11 more)

### Community 209 - "plan_C2.py"
Cohesion: 0.15
Nodes (16): at(), at2(), chan_left(), chan_right(), outward(), pin_xy(), put(), Candidate C2 placement planner (offline aid; the native Altium write,… (+8 more)

### Community 210 - "ape_052111.pas"
Cohesion: 0.26
Nodes (21): AddCutout(), AddPoly(), CloseTo(), CountItems(), CountPolys(), Counts(), Fail(), FindNet() (+13 more)

### Community 211 - "router_command"
Cohesion: 0.04
Nodes (47): allowed_move, component, delta_x_mm, delta_y_mm, base_sha256, explicit_seeds, initial_deletions, C:\\Users\\PMLS\\AppData\\Local\\Programs\\Python\\Python312\\python.exe (+39 more)

### Community 212 - "routed_plans"
Cohesion: 0.05
Nodes (43): hashes, ..\\evidence\\ASTRA_BF_FINAL_BOTH_SEEDS.csv, ..\\evidence\\DRC_C2_6L_BF.json, ..\\evidence\\GEOMETRY_C2_6L_BF.txt, ASTRA_MCU_RX_REINFORCED_ADDS, ASTRA_REP_BA1_ADDS_OK, ASTRA_UART_READY_ADDS, BATCH_C_OK (+35 more)

### Community 213 - "c2lib.py"
Cohesion: 0.15
Nodes (12): gap(), min_gap(), Rule evidence on the SAVED NATIVE C2 state: separations between noise/heat…, bbox_of(), load_b(), Geometry kernel for candidate C2 planning (offline aid; native Altium…, recs: {designator: record}; draws bbox (courtyard proxy) + pads; top grey/blue,…, render() (+4 more)

### Community 214 - "emg_features.py"
Cohesion: 0.29
Nodes (9): _bp_env(), classify(), gather(), load(), main(), median_freq(), mvc_ref(), Return (band-passed signal, RMS envelope in volts). (+1 more)

### Community 215 - "c2audit.py"
Cohesion: 0.23
Nodes (12): audit(), Calibrate the offline audit on candidate B (native DRC: 0 clearance / 0…, gap(), pad_layers(), _padbox(), Offline placement audit for C2 (conservative screening; native Altium DRC is…, ref: the native-verified B placement; a pair whose clearance is not worse than…, summarize() (+4 more)

### Community 216 - "ae_101824.pas"
Cohesion: 0.22
Nodes (19): CloseTo(), Fail(), FindComp(), FindFreePad(), FindKeepout(), FindPoly(), FindRule(), FindTrack() (+11 more)

### Community 217 - "Compact candidate C2 — change audit (26 Sep 2026)"
Cohesion: 0.18
Nodes (10): 1. Result, 2. User decisions this change rests on (26 Sep), 3. Floorplan (x-ray), 4. Rule compliance and the documented departures from R2 "initial" dispositions, 5. Native execution (AD22, proven calls only; every new call proven on a disposable copy first), 6. Verification (saved state, after close/reopen), 7. Routing trial on 4 layers (26 Sep), 8. Open issues (ranked) (+2 more)

### Community 218 - "find_spot"
Cohesion: 0.27
Nodes (9): find_spot(), make(x, y, rot) -> {designator: record}; returns (records, x, y, rot) of the…, spiral(), group_near(), near(), rigid group (B local layout) flipped ('F') or translated ('T'), optionally…, make(), Create candidate C2 (and a disposable API-proof copy) from candidate B's saved… (+1 more)

### Community 219 - "place"
Cohesion: 0.25
Nodes (8): group_transform(), place(), return a new record for part p at final origin/rot/side with re-derived bbox…, rigid group move of B-state members. ('T', dx, dy) translate ('F', cx, cy) flip…, Self-test of c2lib against native truth: rebuild B's flipped/translated groups…, swap_layer(), put_syn(), tc_make()

### Community 220 - "export_geometry_T.pas"
Cohesion: 0.80
Nodes (4): MM(), NetOf(), RectS(), RunFixed()

### Community 221 - "gw_001620.pas"
Cohesion: 0.80
Nodes (4): MM(), NetOf(), RectS(), RunFixed()

### Community 222 - "gx_235734.pas"
Cohesion: 0.80
Nodes (4): MM(), NetOf(), RectS(), RunFixed()

### Community 223 - "gy_000106.pas"
Cohesion: 0.80
Nodes (4): MM(), NetOf(), RectS(), RunFixed()

### Community 224 - "gz_001139.pas"
Cohesion: 0.80
Nodes (4): MM(), NetOf(), RectS(), RunFixed()

### Community 225 - "la_233408.pas"
Cohesion: 0.70
Nodes (4): Count(), NewPad(), RunFixed(), Say()

### Community 226 - "probe_libadd_T.pas"
Cohesion: 0.70
Nodes (4): Count(), NewPad(), RunFixed(), Say()

### Community 227 - "render_c2_native.py"
Cohesion: 0.50
Nodes (3): draw(), outline_of(), Renders FROM THE SAVED NATIVE GEOMETRY (GEOMETRY_*.txt exports), labelled as…

### Community 228 - "lr_233251.pas"
Cohesion: 1.00
Nodes (3): CountPrims(), RunFixed(), Say()

### Community 229 - "exists"
Cohesion: 0.67
Nodes (3): exists, RunFixed(), Say()

### Community 230 - "probe_libread_T.pas"
Cohesion: 1.00
Nodes (3): CountPrims(), RunFixed(), Say()

### Community 231 - "exists"
Cohesion: 0.67
Nodes (3): exists, RunFixed(), Say()

### Community 232 - "routed_plans"
Cohesion: 0.05
Nodes (43): hashes, ..\\evidence\\ASTRA_BGM_TX_SEED_ADDS.csv, ..\\evidence\\DRC_C2_6L_BGM.json, ..\\evidence\\GEOMETRY_C2_6L_BGM.txt, ASTRA_MCU_RX_REINFORCED_ADDS, ASTRA_REP_BA1_ADDS_OK, ASTRA_UART_READY_ADDS, BATCH_C_OK (+35 more)

### Community 233 - "preserved"
Cohesion: 0.10
Nodes (27): detail(), main(), Check only the four BG antenna branches, preserving the L5 interior junction., row(), desc(), main(), Bounded read-only contact and removal review of four new BG antenna tracks., desc() (+19 more)

### Community 261 - "apply_ops_T.pas"
Cohesion: 0.26
Nodes (21): AddCutout(), AddPoly(), CloseTo(), CountItems(), CountPolys(), Counts(), Fail(), FindNet() (+13 more)

### Community 262 - "at_105742.pas"
Cohesion: 0.22
Nodes (19): CloseTo(), Fail(), FindComp(), FindFreePad(), FindKeepout(), FindPoly(), FindRule(), FindTrack() (+11 more)

### Community 263 - "ho_103856.pas"
Cohesion: 0.29
Nodes (19): AddCutout(), AddPoly(), CloseTo(), CountItems(), Counts(), Fail(), FindNet(), FindRule() (+11 more)

### Community 264 - "tc_110641.pas"
Cohesion: 0.29
Nodes (19): AddCutout(), AddPoly(), CloseTo(), CountItems(), Counts(), Fail(), FindNet(), FindRule() (+11 more)

### Community 265 - "tk_110924.pas"
Cohesion: 0.29
Nodes (19): AddCutout(), AddPoly(), CloseTo(), CountItems(), Counts(), Fail(), FindNet(), FindRule() (+11 more)

### Community 266 - "tq_111343.pas"
Cohesion: 0.29
Nodes (19): AddCutout(), AddPoly(), CloseTo(), CountItems(), Counts(), Fail(), FindNet(), FindRule() (+11 more)

### Community 267 - "tr_110331.pas"
Cohesion: 0.29
Nodes (19): AddCutout(), AddPoly(), CloseTo(), CountItems(), Counts(), Fail(), FindNet(), FindRule() (+11 more)

### Community 268 - "tu_111542.pas"
Cohesion: 0.29
Nodes (19): AddCutout(), AddPoly(), CloseTo(), CountItems(), Counts(), Fail(), FindNet(), FindRule() (+11 more)

### Community 269 - "p6c_123528.pas"
Cohesion: 0.26
Nodes (21): AddCutout(), AddPoly(), CloseTo(), CountItems(), CountPolys(), Counts(), Fail(), FindNet() (+13 more)

### Community 270 - "gr3_113947.pas"
Cohesion: 0.80
Nodes (4): MM(), NetOf(), RectS(), RunFixed()

### Community 274 - "gd_110815.pas"
Cohesion: 0.80
Nodes (4): MM(), NetOf(), RectS(), RunFixed()

### Community 275 - "ge_111110.pas"
Cohesion: 0.80
Nodes (4): MM(), NetOf(), RectS(), RunFixed()

### Community 276 - "gf_111511.pas"
Cohesion: 0.80
Nodes (4): MM(), NetOf(), RectS(), RunFixed()

### Community 277 - "gh_104401.pas"
Cohesion: 0.80
Nodes (4): MM(), NetOf(), RectS(), RunFixed()

### Community 278 - "gr_111721.pas"
Cohesion: 0.80
Nodes (4): MM(), NetOf(), RectS(), RunFixed()

### Community 279 - "gt_105859.pas"
Cohesion: 0.80
Nodes (4): MM(), NetOf(), RectS(), RunFixed()

### Community 280 - "prune_from_antennae.py"
Cohesion: 0.60
Nodes (4): end_free(), is_dead(), nbrs(), Remove dangling copper seeded ONLY by Altium's own Net Antennae list (the DRC…

### Community 298 - "p6p_123322.pas"
Cohesion: 0.26
Nodes (21): AddCutout(), AddPoly(), CloseTo(), CountItems(), CountPolys(), Counts(), Fail(), FindNet() (+13 more)

### Community 299 - "a6o_213811.pas"
Cohesion: 0.26
Nodes (21): AddCutout(), AddPoly(), CloseTo(), CountItems(), CountPolys(), Counts(), Fail(), FindNet() (+13 more)

### Community 300 - "a6b_155432.pas"
Cohesion: 0.26
Nodes (21): AddCutout(), AddPoly(), CloseTo(), CountItems(), CountPolys(), Counts(), Fail(), FindNet() (+13 more)

### Community 301 - "stitch.py"
Cohesion: 0.22
Nodes (8): near_pad(), ok(), Plane stitching for C2 6L: every copper group of GND that reaches no via /…, 0.45/0.2 via at the pad centre (filled + capped, POFV); the pad must be >= 0.5…, any pad (any net, own pad included) within 0.1 mm of g - build_ops' 'via on…, tkey(), try_pad(), via_in_pad()

### Community 302 - "a6c_163445.pas"
Cohesion: 0.26
Nodes (21): AddCutout(), AddPoly(), CloseTo(), CountItems(), CountPolys(), Counts(), Fail(), FindNet() (+13 more)

### Community 303 - "s6c_123459.pas"
Cohesion: 0.62
Nodes (6): Cu(), Diel(), Dump(), Order(), RunFixed(), Say()

### Community 304 - "s6d_120322.pas"
Cohesion: 0.62
Nodes (6): Cu(), Diel(), Dump(), Order(), RunFixed(), Say()

### Community 305 - "s6e_121023.pas"
Cohesion: 0.62
Nodes (6): Cu(), Diel(), Dump(), Order(), RunFixed(), Say()

### Community 306 - "s6f_122250.pas"
Cohesion: 0.62
Nodes (6): Cu(), Diel(), Dump(), Order(), RunFixed(), Say()

### Community 307 - "s6g_123036.pas"
Cohesion: 0.62
Nodes (6): Cu(), Diel(), Dump(), Order(), RunFixed(), Say()

### Community 308 - "stack6_T.pas"
Cohesion: 0.62
Nodes (6): Cu(), Diel(), Dump(), Order(), RunFixed(), Say()

### Community 309 - "plan_bk13_escape_c2.py"
Cohesion: 0.33
Nodes (3): pattern(), BK13 (0.35 mm pitch) socket escape pattern, identical for J_FPC1..5. Top row 1…, v2: keepout-clearance-correct (0.13 mm to the between-row keepout), 0.15 mm…

### Community 310 - "g6_123554.pas"
Cohesion: 0.80
Nodes (4): MM(), NetOf(), RectS(), RunFixed()

### Community 311 - "g6a_133240.pas"
Cohesion: 0.80
Nodes (4): MM(), NetOf(), RectS(), RunFixed()

### Community 312 - "dru_123247.pas"
Cohesion: 0.83
Nodes (3): LName(), RunFixed(), Say()

### Community 313 - "dump_rules_T.pas"
Cohesion: 0.83
Nodes (3): LName(), RunFixed(), Say()

### Community 321 - "ddl_155255.pas"
Cohesion: 0.26
Nodes (21): AddCutout(), AddPoly(), CloseTo(), CountItems(), CountPolys(), Counts(), Fail(), FindNet() (+13 more)

### Community 322 - "kop_154628.pas"
Cohesion: 0.26
Nodes (21): AddCutout(), AddPoly(), CloseTo(), CountItems(), CountPolys(), Counts(), Fail(), FindNet() (+13 more)

### Community 323 - "p6c2_155904.pas"
Cohesion: 0.26
Nodes (21): AddCutout(), AddPoly(), CloseTo(), CountItems(), CountPolys(), Counts(), Fail(), FindNet() (+13 more)

### Community 324 - "p6e_163638.pas"
Cohesion: 0.26
Nodes (21): AddCutout(), AddPoly(), CloseTo(), CountItems(), CountPolys(), Counts(), Fail(), FindNet() (+13 more)

### Community 325 - "md2_155729.pas"
Cohesion: 0.22
Nodes (19): CloseTo(), Fail(), FindComp(), FindFreePad(), FindKeepout(), FindPoly(), FindRule(), FindTrack() (+11 more)

### Community 326 - "mdl_155321.pas"
Cohesion: 0.22
Nodes (19): CloseTo(), Fail(), FindComp(), FindFreePad(), FindKeepout(), FindPoly(), FindRule(), FindTrack() (+11 more)

### Community 327 - "gaf_052111.pas"
Cohesion: 0.80
Nodes (4): MM(), NetOf(), RectS(), RunFixed()

### Community 329 - "a6g_171008.pas"
Cohesion: 0.26
Nodes (21): AddCutout(), AddPoly(), CloseTo(), CountItems(), CountPolys(), Counts(), Fail(), FindNet() (+13 more)

### Community 330 - "relocate_drl.py"
Cohesion: 0.33
Nodes (4): legal(), local_pads(), Move the 15 DNP DRL input resistors (R_DRL_VAn/VBn/VCn) out of the BK13 socket…, pad copper polygons in the component frame (origin at the component centre,…

### Community 331 - "g6b_155350.pas"
Cohesion: 0.80
Nodes (4): MM(), NetOf(), RectS(), RunFixed()

### Community 332 - "g6c_155819.pas"
Cohesion: 0.80
Nodes (4): MM(), NetOf(), RectS(), RunFixed()

### Community 333 - "g6d_155951.pas"
Cohesion: 0.80
Nodes (4): MM(), NetOf(), RectS(), RunFixed()

### Community 334 - "g6e_163611.pas"
Cohesion: 0.80
Nodes (4): MM(), NetOf(), RectS(), RunFixed()

### Community 335 - "g6f_163746.pas"
Cohesion: 0.80
Nodes (4): MM(), NetOf(), RectS(), RunFixed()

### Community 345 - "a6h_181848.pas"
Cohesion: 0.26
Nodes (21): AddCutout(), AddPoly(), CloseTo(), CountItems(), CountPolys(), Counts(), Fail(), FindNet() (+13 more)

### Community 346 - "a6j_190538.pas"
Cohesion: 0.26
Nodes (21): AddCutout(), AddPoly(), CloseTo(), CountItems(), CountPolys(), Counts(), Fail(), FindNet() (+13 more)

### Community 347 - "a6m_193630.pas"
Cohesion: 0.26
Nodes (21): AddCutout(), AddPoly(), CloseTo(), CountItems(), CountPolys(), Counts(), Fail(), FindNet() (+13 more)

### Community 348 - "p6h_182535.pas"
Cohesion: 0.26
Nodes (21): AddCutout(), AddPoly(), CloseTo(), CountItems(), CountPolys(), Counts(), Fail(), FindNet() (+13 more)

### Community 349 - "p6k_191112.pas"
Cohesion: 0.26
Nodes (21): AddCutout(), AddPoly(), CloseTo(), CountItems(), CountPolys(), Counts(), Fail(), FindNet() (+13 more)

### Community 350 - "rgp_194117.pas"
Cohesion: 0.26
Nodes (21): AddCutout(), AddPoly(), CloseTo(), CountItems(), CountPolys(), Counts(), Fail(), FindNet() (+13 more)

### Community 351 - "rin_190641.pas"
Cohesion: 0.26
Nodes (21): AddCutout(), AddPoly(), CloseTo(), CountItems(), CountPolys(), Counts(), Fail(), FindNet() (+13 more)

### Community 352 - "apr_202815.pas"
Cohesion: 0.26
Nodes (21): AddCutout(), AddPoly(), CloseTo(), CountItems(), CountPolys(), Counts(), Fail(), FindNet() (+13 more)

### Community 353 - "C2 6-layer routing completion — resume note (keep this file current)"
Cohesion: 0.05
Nodes (36): Astra update — 27 Sep 2026, 19:10 local (actual native timestamps), Astra update — 27 September 2026, state BB, C2 6-layer routing completion — resume note (keep this file current), CURRENT — Astra BF, 27 Sep2026, native DRC completed21:22:37local, CURRENT: BJ — routing complete and all-trace checks, 27 September 2026, HANDOFF 21:xx (27 Sep): work paused by the user and handed to Astra -> read `HANDOFF_ASTRA_2026-09-27.md` first, How to run things (work/), Plan agreed with the user (13:xx 27 Sep) - do in this order after the current round is written (+28 more)

### Community 354 - "g6g_171149.pas"
Cohesion: 0.80
Nodes (4): MM(), NetOf(), RectS(), RunFixed()

### Community 355 - "g6h_182354.pas"
Cohesion: 0.80
Nodes (4): MM(), NetOf(), RectS(), RunFixed()

### Community 356 - "g6i_182649.pas"
Cohesion: 0.80
Nodes (4): MM(), NetOf(), RectS(), RunFixed()

### Community 357 - "g6j_190611.pas"
Cohesion: 0.80
Nodes (4): MM(), NetOf(), RectS(), RunFixed()

### Community 358 - "g6k_191049.pas"
Cohesion: 0.80
Nodes (4): MM(), NetOf(), RectS(), RunFixed()

### Community 359 - "g6l_191206.pas"
Cohesion: 0.80
Nodes (4): MM(), NetOf(), RectS(), RunFixed()

### Community 360 - "g6m2_194006.pas"
Cohesion: 0.80
Nodes (4): MM(), NetOf(), RectS(), RunFixed()

### Community 361 - "g6m_193659.pas"
Cohesion: 0.80
Nodes (4): MM(), NetOf(), RectS(), RunFixed()

### Community 362 - "ggp_195007.pas"
Cohesion: 0.80
Nodes (4): MM(), NetOf(), RectS(), RunFixed()

### Community 380 - "repair.py"
Cohesion: 0.05
Nodes (63): access_mask(), bk13_groups(), commit_exact(), _dead(), disk(), exact_ok(), _fail(), fixed_path_victims() (+55 more)

### Community 381 - "a6p_220109.pas"
Cohesion: 0.26
Nodes (21): AddCutout(), AddPoly(), CloseTo(), CountItems(), CountPolys(), Counts(), Fail(), FindNet() (+13 more)

### Community 382 - "g6n_202946.pas"
Cohesion: 0.80
Nodes (4): MM(), NetOf(), RectS(), RunFixed()

### Community 387 - "a6q_221928.pas"
Cohesion: 0.26
Nodes (21): AddCutout(), AddPoly(), CloseTo(), CountItems(), CountPolys(), Counts(), Fail(), FindNet() (+13 more)

### Community 388 - "mch_220109.pas"
Cohesion: 0.22
Nodes (19): CloseTo(), Fail(), FindComp(), FindFreePad(), FindKeepout(), FindPoly(), FindRule(), FindTrack() (+11 more)

### Community 389 - "a6s_232727.pas"
Cohesion: 0.26
Nodes (21): AddCutout(), AddPoly(), CloseTo(), CountItems(), CountPolys(), Counts(), Fail(), FindNet() (+13 more)

### Community 390 - "a6r_225457.pas"
Cohesion: 0.26
Nodes (21): AddCutout(), AddPoly(), CloseTo(), CountItems(), CountPolys(), Counts(), Fail(), FindNet() (+13 more)

### Community 391 - "place_part.py"
Cohesion: 0.40
Nodes (3): body_abs(), local(), Legal-spot search / check for single parts on one face (placement nudges). A…

### Community 392 - "g6o_214442.pas"
Cohesion: 0.80
Nodes (4): MM(), NetOf(), RectS(), RunFixed()

### Community 393 - "g6p_220109.pas"
Cohesion: 0.80
Nodes (4): MM(), NetOf(), RectS(), RunFixed()

### Community 394 - "g6q_221928.pas"
Cohesion: 0.80
Nodes (4): MM(), NetOf(), RectS(), RunFixed()

### Community 400 - "a6t_001212.pas"
Cohesion: 0.26
Nodes (21): AddCutout(), AddPoly(), CloseTo(), CountItems(), CountPolys(), Counts(), Fail(), FindNet() (+13 more)

### Community 401 - "g6r_225457.pas"
Cohesion: 0.80
Nodes (4): MM(), NetOf(), RectS(), RunFixed()

### Community 402 - "ConsistentRepairTests"
Cohesion: 0.10
Nodes (19): checked_drops(), main(), make_consistent(), Check repair.py output, dropping failed repairs together with victim reroutes.…, --drop-bad deliberately returns 0 for removable geometric problems., read_rows(), repair_id(), RepairCheckError (+11 more)

### Community 405 - "a6u_004421.pas"
Cohesion: 0.26
Nodes (21): AddCutout(), AddPoly(), CloseTo(), CountItems(), CountPolys(), Counts(), Fail(), FindNet() (+13 more)

### Community 406 - "g6s_232727.pas"
Cohesion: 0.80
Nodes (4): MM(), NetOf(), RectS(), RunFixed()

### Community 407 - "g6t_001212.pas"
Cohesion: 0.80
Nodes (4): MM(), NetOf(), RectS(), RunFixed()

### Community 413 - "a6v_012437.pas"
Cohesion: 0.26
Nodes (21): AddCutout(), AddPoly(), CloseTo(), CountItems(), CountPolys(), Counts(), Fail(), FindNet() (+13 more)

### Community 414 - "g6u_004421.pas"
Cohesion: 0.80
Nodes (4): MM(), NetOf(), RectS(), RunFixed()

### Community 417 - "apx_033252.pas"
Cohesion: 0.26
Nodes (21): AddCutout(), AddPoly(), CloseTo(), CountItems(), CountPolys(), Counts(), Fail(), FindNet() (+13 more)

### Community 418 - "g6v_012438.pas"
Cohesion: 0.80
Nodes (4): MM(), NetOf(), RectS(), RunFixed()

### Community 421 - "prx_033722.pas"
Cohesion: 0.26
Nodes (21): AddCutout(), AddPoly(), CloseTo(), CountItems(), CountPolys(), Counts(), Fail(), FindNet() (+13 more)

### Community 422 - "pry_033832.pas"
Cohesion: 0.26
Nodes (21): AddCutout(), AddPoly(), CloseTo(), CountItems(), CountPolys(), Counts(), Fail(), FindNet() (+13 more)

### Community 423 - "rrg_024216.pas"
Cohesion: 0.26
Nodes (21): AddCutout(), AddPoly(), CloseTo(), CountItems(), CountPolys(), Counts(), Fail(), FindNet() (+13 more)

### Community 424 - "mrg_024217.pas"
Cohesion: 0.22
Nodes (19): CloseTo(), Fail(), FindComp(), FindFreePad(), FindKeepout(), FindPoly(), FindRule(), FindTrack() (+11 more)

### Community 425 - "apa_040850.pas"
Cohesion: 0.26
Nodes (21): AddCutout(), AddPoly(), CloseTo(), CountItems(), CountPolys(), Counts(), Fail(), FindNet() (+13 more)

### Community 426 - "g6w_024217.pas"
Cohesion: 0.80
Nodes (4): MM(), NetOf(), RectS(), RunFixed()

### Community 427 - "g6x_033252.pas"
Cohesion: 0.80
Nodes (4): MM(), NetOf(), RectS(), RunFixed()

### Community 428 - "g6y_033722.pas"
Cohesion: 0.80
Nodes (4): MM(), NetOf(), RectS(), RunFixed()

### Community 429 - "g6z_033832.pas"
Cohesion: 0.80
Nodes (4): MM(), NetOf(), RectS(), RunFixed()

### Community 437 - "apc_044145.pas"
Cohesion: 0.26
Nodes (21): AddCutout(), AddPoly(), CloseTo(), CountItems(), CountPolys(), Counts(), Fail(), FindNet() (+13 more)

### Community 438 - "pra_041418.pas"
Cohesion: 0.26
Nodes (21): AddCutout(), AddPoly(), CloseTo(), CountItems(), CountPolys(), Counts(), Fail(), FindNet() (+13 more)

### Community 439 - "aph_063917.pas"
Cohesion: 0.26
Nodes (21): AddCutout(), AddPoly(), CloseTo(), CountItems(), CountPolys(), Counts(), Fail(), FindNet() (+13 more)

### Community 440 - "gaa_040850.pas"
Cohesion: 0.80
Nodes (4): MM(), NetOf(), RectS(), RunFixed()

### Community 441 - "gab_041418.pas"
Cohesion: 0.80
Nodes (4): MM(), NetOf(), RectS(), RunFixed()

### Community 442 - "gac_044145.pas"
Cohesion: 0.80
Nodes (4): MM(), NetOf(), RectS(), RunFixed()

### Community 450 - "rpg_055739.pas"
Cohesion: 0.26
Nodes (21): AddCutout(), AddPoly(), CloseTo(), CountItems(), CountPolys(), Counts(), Fail(), FindNet() (+13 more)

### Community 451 - "mvg_055739.pas"
Cohesion: 0.22
Nodes (19): CloseTo(), Fail(), FindComp(), FindFreePad(), FindKeepout(), FindPoly(), FindRule(), FindTrack() (+11 more)

### Community 452 - "asw_124433.pas"
Cohesion: 0.26
Nodes (21): AddCutout(), AddPoly(), CloseTo(), CountItems(), CountPolys(), Counts(), Fail(), FindNet() (+13 more)

### Community 453 - "mcb_123711.pas"
Cohesion: 0.22
Nodes (19): CloseTo(), Fail(), FindComp(), FindFreePad(), FindKeepout(), FindPoly(), FindRule(), FindTrack() (+11 more)

### Community 454 - "gloss.py"
Cohesion: 0.18
Nodes (5): has_unpreserved_contact(), octi_paths(), Gloss / straighten router copper (the "professional look" pass). For every net…, simple octilinear candidates from a to b (lists of points), fewest segments…, Reject body contacts unless the other object also covers a retained endpoint.…

### Community 455 - "gag_055739.pas"
Cohesion: 0.80
Nodes (4): MM(), NetOf(), RectS(), RunFixed()

### Community 456 - "gah_063917.pas"
Cohesion: 0.80
Nodes (4): MM(), NetOf(), RectS(), RunFixed()

### Community 462 - "api_073926.pas"
Cohesion: 0.26
Nodes (21): AddCutout(), AddPoly(), CloseTo(), CountItems(), CountPolys(), Counts(), Fail(), FindNet() (+13 more)

### Community 463 - "apn_105426.pas"
Cohesion: 0.26
Nodes (21): AddCutout(), AddPoly(), CloseTo(), CountItems(), CountPolys(), Counts(), Fail(), FindNet() (+13 more)

### Community 464 - "rtp_095144.pas"
Cohesion: 0.26
Nodes (21): AddCutout(), AddPoly(), CloseTo(), CountItems(), CountPolys(), Counts(), Fail(), FindNet() (+13 more)

### Community 465 - "gai_073926.pas"
Cohesion: 0.80
Nodes (4): MM(), NetOf(), RectS(), RunFixed()

### Community 468 - "apj_083031.pas"
Cohesion: 0.26
Nodes (21): AddCutout(), AddPoly(), CloseTo(), CountItems(), CountPolys(), Counts(), Fail(), FindNet() (+13 more)

### Community 469 - "apl_094611.pas"
Cohesion: 0.26
Nodes (21): AddCutout(), AddPoly(), CloseTo(), CountItems(), CountPolys(), Counts(), Fail(), FindNet() (+13 more)

### Community 470 - "prj_083356.pas"
Cohesion: 0.26
Nodes (21): AddCutout(), AddPoly(), CloseTo(), CountItems(), CountPolys(), Counts(), Fail(), FindNet() (+13 more)

### Community 471 - "gaj_083031.pas"
Cohesion: 0.80
Nodes (4): MM(), NetOf(), RectS(), RunFixed()

### Community 472 - "gak_083357.pas"
Cohesion: 0.80
Nodes (4): MM(), NetOf(), RectS(), RunFixed()

### Community 473 - "gal_094611.pas"
Cohesion: 0.80
Nodes (4): MM(), NetOf(), RectS(), RunFixed()

### Community 479 - "mtp_095144.pas"
Cohesion: 0.22
Nodes (19): CloseTo(), Fail(), FindComp(), FindFreePad(), FindKeepout(), FindPoly(), FindRule(), FindTrack() (+11 more)

### Community 480 - "gam_095144.pas"
Cohesion: 0.80
Nodes (4): MM(), NetOf(), RectS(), RunFixed()

### Community 481 - "gan_105426.pas"
Cohesion: 0.80
Nodes (4): MM(), NetOf(), RectS(), RunFixed()

### Community 485 - "gao_123712.pas"
Cohesion: 0.80
Nodes (4): MM(), NetOf(), RectS(), RunFixed()

### Community 486 - "gap_124242.pas"
Cohesion: 0.80
Nodes (4): MM(), NetOf(), RectS(), RunFixed()

### Community 487 - "gaq_124433.pas"
Cohesion: 0.80
Nodes (4): MM(), NetOf(), RectS(), RunFixed()

### Community 494 - "aup_135846.pas"
Cohesion: 0.26
Nodes (21): AddCutout(), AddPoly(), CloseTo(), CountItems(), CountPolys(), Counts(), Fail(), FindNet() (+13 more)

### Community 495 - "rcb_135636.pas"
Cohesion: 0.26
Nodes (21): AddCutout(), AddPoly(), CloseTo(), CountItems(), CountPolys(), Counts(), Fail(), FindNet() (+13 more)

### Community 496 - "rrn_125439.pas"
Cohesion: 0.26
Nodes (21): AddCutout(), AddPoly(), CloseTo(), CountItems(), CountPolys(), Counts(), Fail(), FindNet() (+13 more)

### Community 497 - "apw_151610.pas"
Cohesion: 0.26
Nodes (21): AddCutout(), AddPoly(), CloseTo(), CountItems(), CountPolys(), Counts(), Fail(), FindNet() (+13 more)

### Community 498 - "mcbt_135637.pas"
Cohesion: 0.22
Nodes (19): CloseTo(), Fail(), FindComp(), FindFreePad(), FindKeepout(), FindPoly(), FindRule(), FindTrack() (+11 more)

### Community 499 - "mr2_125917.pas"
Cohesion: 0.22
Nodes (19): CloseTo(), Fail(), FindComp(), FindFreePad(), FindKeepout(), FindPoly(), FindRule(), FindTrack() (+11 more)

### Community 500 - "mrn_125439.pas"
Cohesion: 0.22
Nodes (19): CloseTo(), Fail(), FindComp(), FindFreePad(), FindKeepout(), FindPoly(), FindRule(), FindTrack() (+11 more)

### Community 501 - "gav_151610.pas"
Cohesion: 0.80
Nodes (4): MM(), NetOf(), RectS(), RunFixed()

### Community 506 - "msk_161919.pas"
Cohesion: 0.22
Nodes (19): CloseTo(), Fail(), FindComp(), FindFreePad(), FindKeepout(), FindPoly(), FindRule(), FindTrack() (+11 more)

### Community 507 - "gar_125439.pas"
Cohesion: 0.80
Nodes (4): MM(), NetOf(), RectS(), RunFixed()

### Community 508 - "gas_125917.pas"
Cohesion: 0.80
Nodes (4): MM(), NetOf(), RectS(), RunFixed()

### Community 509 - "gat_135637.pas"
Cohesion: 0.80
Nodes (4): MM(), NetOf(), RectS(), RunFixed()

### Community 510 - "gau_135846.pas"
Cohesion: 0.80
Nodes (4): MM(), NetOf(), RectS(), RunFixed()

### Community 514 - "pinswap_T.pas"
Cohesion: 0.53
Nodes (8): FindComp(), FindNet(), Mi(), PadNet(), RunFixed(), Say(), SwapPads(), SwapSchematic()

### Community 515 - "psw_161601.pas"
Cohesion: 0.53
Nodes (8): FindComp(), FindNet(), Mi(), PadNet(), RunFixed(), Say(), SwapPads(), SwapSchematic()

### Community 516 - "psw_161614.pas"
Cohesion: 0.53
Nodes (8): FindComp(), FindNet(), Mi(), PadNet(), RunFixed(), Say(), SwapPads(), SwapSchematic()

### Community 517 - "gaw_161651.pas"
Cohesion: 0.80
Nodes (4): MM(), NetOf(), RectS(), RunFixed()

### Community 518 - "gax_161919.pas"
Cohesion: 0.80
Nodes (4): MM(), NetOf(), RectS(), RunFixed()

### Community 519 - "sch_dump_T.pas"
Cohesion: 0.83
Nodes (3): Mi(), RunFixed(), Say()

### Community 520 - "sdm_155058.pas"
Cohesion: 0.83
Nodes (3): Mi(), RunFixed(), Say()

### Community 524 - "apu_163913.pas"
Cohesion: 0.26
Nodes (21): AddCutout(), AddPoly(), CloseTo(), CountItems(), CountPolys(), Counts(), Fail(), FindNet() (+13 more)

### Community 525 - "apz_173925.pas"
Cohesion: 0.26
Nodes (21): AddCutout(), AddPoly(), CloseTo(), CountItems(), CountPolys(), Counts(), Fail(), FindNet() (+13 more)

### Community 526 - "Handoff to Astra — C2 6-layer EMG main board: finish the routing (27 Sep 2026, 21:xx)"
Cohesion: 0.08
Nodes (22): Finishing-tool readiness — read-only review, 27 September 2026, Gloss: usable generator, with specific limitations, Repair-checker failure handling fixed separately from CAD, Silk: no ready cleanup writer in this project, Via rule and batch-category API readiness, Width pass: native setter exists; automatic sizing planner does not, Repair-checker regression evidence, BA inventory and DRC coverage (+14 more)

### Community 527 - "uartswap_T.pas"
Cohesion: 0.15
Nodes (29): w, AddLabel(), At(), FindComp(), FindNet(), Mi(), Nets(), PadNet() (+21 more)

### Community 528 - "router_command"
Cohesion: 0.05
Nodes (38): C:\\Users\\PMLS\\AppData\\Local\\Programs\\Python\\Python312\\python.exe, ..\\evidence\\ASTRA_REP_BA1_ADDS_OK.csv, ..\\evidence\\BATCH_C_OK.csv, ..\\evidence\\MERGE_G_ADDS_OK.csv, ..\\evidence\\MERGE_I_ADDS_OK.csv, ..\\evidence\\REG_ANA_ADDS_OK.csv, ..\\evidence\\REG_MCU_ADDS_OK.csv, ..\\evidence\\REP_AC_ADDS_OK.csv (+30 more)

### Community 529 - "gaz_173925.pas"
Cohesion: 0.80
Nodes (4): MM(), NetOf(), RectS(), RunFixed()

### Community 533 - "gay_163913.pas"
Cohesion: 0.80
Nodes (4): MM(), NetOf(), RectS(), RunFixed()

### Community 534 - "sdm2_162742.pas"
Cohesion: 0.83
Nodes (3): Mi(), RunFixed(), Say()

### Community 540 - "astra_verify_routing_delta.py"
Cohesion: 0.14
Nodes (21): Four short exact-collision alternatives for the CS candidate's thin 3V3 feed., Read-only proof before pruning two obsolete power-stub tracks in a proposal., check_free_pad_translations(), check_translations(), counter_difference(), counts(), geometry(), key() (+13 more)

### Community 541 - ".check"
Cohesion: 0.13
Nodes (3): FreePadTranslationVerification, Small native-export fixtures exercise the authorized translation boundary., TranslationVerification

### Community 542 - "astra_verify_via_rule_delta.py"
Cohesion: 0.20
Nodes (13): byte_diagnostic(), compare(), framed_binary_records(), main(), masked(), Read-only saved-board verification of the authorized BH-to-BI rule edit. Allows…, Diagnostic only: accept observed tag/u32-length framing iff header agrees., selection() (+5 more)

### Community 543 - "astra_apba_185646.pas"
Cohesion: 0.26
Nodes (21): AddCutout(), AddPoly(), CloseTo(), CountItems(), CountPolys(), Counts(), Fail(), FindNet() (+13 more)

### Community 544 - "astra_apbb_191935.pas"
Cohesion: 0.26
Nodes (21): AddCutout(), AddPoly(), CloseTo(), CountItems(), CountPolys(), Counts(), Fail(), FindNet() (+13 more)

### Community 545 - "astra_apbc_200754.pas"
Cohesion: 0.26
Nodes (21): AddCutout(), AddPoly(), CloseTo(), CountItems(), CountPolys(), Counts(), Fail(), FindNet() (+13 more)

### Community 546 - "astra_apbd_202424.pas"
Cohesion: 0.26
Nodes (21): AddCutout(), AddPoly(), CloseTo(), CountItems(), CountPolys(), Counts(), Fail(), FindNet() (+13 more)

### Community 547 - "astra_apbe_204152.pas"
Cohesion: 0.26
Nodes (21): AddCutout(), AddPoly(), CloseTo(), CountItems(), CountPolys(), Counts(), Fail(), FindNet() (+13 more)

### Community 548 - "astra_apbe_ready_205633.pas"
Cohesion: 0.26
Nodes (21): AddCutout(), AddPoly(), CloseTo(), CountItems(), CountPolys(), Counts(), Fail(), FindNet() (+13 more)

### Community 549 - "astra_apbf_final_211832.pas"
Cohesion: 0.26
Nodes (21): AddCutout(), AddPoly(), CloseTo(), CountItems(), CountPolys(), Counts(), Fail(), FindNet() (+13 more)

### Community 550 - "astra_apbf_ready_211056.pas"
Cohesion: 0.26
Nodes (21): AddCutout(), AddPoly(), CloseTo(), CountItems(), CountPolys(), Counts(), Fail(), FindNet() (+13 more)

### Community 551 - "astra_apbg_220654.pas"
Cohesion: 0.26
Nodes (21): AddCutout(), AddPoly(), CloseTo(), CountItems(), CountPolys(), Counts(), Fail(), FindNet() (+13 more)

### Community 552 - "astra_apbg_final_222332.pas"
Cohesion: 0.26
Nodes (21): AddCutout(), AddPoly(), CloseTo(), CountItems(), CountPolys(), Counts(), Fail(), FindNet() (+13 more)

### Community 553 - "astra_apbg_rebased_223912.pas"
Cohesion: 0.26
Nodes (21): AddCutout(), AddPoly(), CloseTo(), CountItems(), CountPolys(), Counts(), Fail(), FindNet() (+13 more)

### Community 554 - "astra_apbh_225024.pas"
Cohesion: 0.26
Nodes (21): AddCutout(), AddPoly(), CloseTo(), CountItems(), CountPolys(), Counts(), Fail(), FindNet() (+13 more)

### Community 555 - "astra_apbh_centered_225113.pas"
Cohesion: 0.26
Nodes (21): AddCutout(), AddPoly(), CloseTo(), CountItems(), CountPolys(), Counts(), Fail(), FindNet() (+13 more)

### Community 556 - "astra_apbj_230930.pas"
Cohesion: 0.26
Nodes (21): AddCutout(), AddPoly(), CloseTo(), CountItems(), CountPolys(), Counts(), Fail(), FindNet() (+13 more)

### Community 557 - "drc"
Cohesion: 0.15
Nodes (16): main(), Read-only verification of the bounded BI-to-BJ antenna cleanup., sha(), main(), Read-only native BFS-to-BG verification preserving the saved user trace edit., sha(), main(), Read-only native BE-to-BF review of the final reinforced MCU RX candidate. (+8 more)

### Community 558 - "GlossContactTests"
Cohesion: 0.27
Nodes (5): dogleg(), GlossContactTests, pad(), Small synthetic regressions; never load board geometry or launch native CAD., track()

### Community 559 - "astra_audit_trace_rules.py"
Cohesion: 0.23
Nodes (14): audit(), choose_rule(), main(), mm(), net_classes(), Read-only audit of every exported free copper track and via against saved…, scope_matches(), text_records() (+6 more)

### Community 560 - "NativeTraceRuleTests"
Cohesion: 0.28
Nodes (5): NativeTraceRuleTests, Small rule-selection regressions; no PCB file, CAD, router or geometry engine., rule(), track(), via()

### Community 561 - "inventory"
Cohesion: 0.29
Nodes (7): copper_layer(), inventory(), main(), Informational inventory of exported free copper tracks; never edits CAD.…, Focused cases for an informational, export-precision copper inventory., track(), TrackShapeInventoryTests

### Community 562 - "explicit_seed"
Cohesion: 0.18
Nodes (11): explicit_seed, conn, d, group, kind, net, relax, x1 (+3 more)

### Community 563 - "ASTRA_BF_CS_BOTTOM_PLANNING_ONLY/MANIFEST.json"
Cohesion: 0.20
Nodes (9): hashes, ..\\evidence\\ASTRA_BF_CS_ESCAPE_SEED_ADDS.csv, ..\\evidence\\DRC_C2_6L_BF.json, ..\\evidence\\GEOMETRY_C2_6L_BF.txt, native_base, native_drc, seed, seed_rows (+1 more)

### Community 564 - "ASTRA_BF_CS_SEEDED_PLANNING_ONLY/MANIFEST.json"
Cohesion: 0.20
Nodes (9): hashes, ..\\evidence\\ASTRA_BF_CS_ESCAPE_SEED_ADDS.csv, ..\\evidence\\DRC_C2_6L_BF.json, ..\\evidence\\GEOMETRY_C2_6L_BF.txt, native_base, native_drc, seed, seed_rows (+1 more)

### Community 565 - "ASTRA_BF_TX_SEEDED_PLANNING_ONLY/MANIFEST.json"
Cohesion: 0.20
Nodes (9): hashes, ..\\evidence\\ASTRA_BF_TX_LINK_ESCAPE_SEED_ADDS.csv, ..\\evidence\\DRC_C2_6L_BF.json, ..\\evidence\\GEOMETRY_C2_6L_BF.txt, native_base, native_drc, seed, seed_rows (+1 more)

### Community 566 - "astra_verify_pcb_structure.py"
Cohesion: 0.36
Nodes (9): board_group(), body_diagnostic(), compare(), main(), Read-only protected-stream comparison for a saved Altium routing-only edit.…, Explain model metadata differences without waiving raw-byte failures., sha(), snapshot() (+1 more)

### Community 567 - "ASTRA_CH4_LOCAL2_PLANNING_ONLY/MANIFEST.json"
Cohesion: 0.22
Nodes (8): allowed_move, component, delta_x_mm, delta_y_mm, base_sha256, initial_deletions, native_base, status

### Community 568 - "astra_align_via_rule_T.pas"
Cohesion: 0.50
Nodes (8): AuditVias(), CheckPreserved(), FindExactRule(), LogRule(), NearMM(), RuleCount(), RunFixed(), Say()

### Community 569 - "astra_viabi_225318.pas"
Cohesion: 0.50
Nodes (8): AuditVias(), CheckPreserved(), FindExactRule(), LogRule(), NearMM(), RuleCount(), RunFixed(), Say()

### Community 570 - "All free trace audit and via evidence — 2026-09-27"
Cohesion: 0.29
Nodes (6): All free trace audit and via evidence — 2026-09-27, Five outline findings, Informational shape inventory, JLCPCB primary sources, Native DRC coverage, Saved rule audit

### Community 571 - "Channel 4 routing correction — native checkpoint BC"
Cohesion: 0.29
Nodes (6): Actual DRC disposition, Applied correction, Channel 4 routing correction — native checkpoint BC, Native evidence, Next work, Preservation limitations

### Community 572 - "Routing completion and all-trace check — BJ, 27 September 2026"
Cohesion: 0.29
Nodes (6): Actual final checks, Changes actually made, Evidence and next operation, Open this project, Remaining work and limits, Routing completion and all-trace check — BJ, 27 September 2026

### Community 574 - "BF testpad relocation and MCU92 escape: planning evidence"
Cohesion: 0.33
Nodes (5): BF testpad relocation and MCU92 escape: planning evidence, Exact sources, Joint pending-CS result, Limits, Saved-BF pad-only move

### Community 575 - "All-trace verification coverage review"
Cohesion: 0.40
Nodes (4): All-trace verification coverage review, Gloss and finishing are not all-trace electrical verification, Native coverage: width and clearance present; categories 9 and 11 absent, Offline checks cover different, narrower questions

### Community 576 - "Gloss contact guard: code and synthetic test evidence, 27 September 2026"
Cohesion: 0.40
Nodes (4): Changes, Focused test result, Gloss contact guard: code and synthetic test evidence, 27 September 2026, Limits and integration

### Community 577 - "Guided partial-rip corridor and seed plan inputs, 27 September 2026"
Cohesion: 0.40
Nodes (4): Guided partial-rip corridor and seed plan inputs, 27 September 2026, Planner correction, Seed wrapper correction, Test evidence

### Community 578 - "MCU UART RX routed — native checkpoint BF"
Cohesion: 0.40
Nodes (4): Actual applied change, Current checkpoint, MCU UART RX routed — native checkpoint BF, Measured evidence

### Community 579 - "Radio UART RX routed — native checkpoint BE"
Cohesion: 0.40
Nodes (4): Applied change, Continuation, Radio UART RX routed — native checkpoint BE, Verification

### Community 580 - "Vc_1 native routing checkpoint BD — 27 September 2026"
Cohesion: 0.40
Nodes (4): Applied change, Limits and continuation, Native results, Vc_1 native routing checkpoint BD — 27 September 2026

### Community 581 - "astra_gaz_185646.pas"
Cohesion: 0.80
Nodes (4): MM(), NetOf(), RectS(), RunFixed()

### Community 582 - "astra_gba_185646.pas"
Cohesion: 0.80
Nodes (4): MM(), NetOf(), RectS(), RunFixed()

### Community 583 - "astra_gbb_191935.pas"
Cohesion: 0.80
Nodes (4): MM(), NetOf(), RectS(), RunFixed()

### Community 584 - "astra_gbc_200755.pas"
Cohesion: 0.80
Nodes (4): MM(), NetOf(), RectS(), RunFixed()

### Community 585 - "astra_gbd_202424.pas"
Cohesion: 0.80
Nodes (4): MM(), NetOf(), RectS(), RunFixed()

### Community 586 - "astra_gbe_204152.pas"
Cohesion: 0.80
Nodes (4): MM(), NetOf(), RectS(), RunFixed()

### Community 587 - "astra_gbf_210912.pas"
Cohesion: 0.80
Nodes (4): MM(), NetOf(), RectS(), RunFixed()

### Community 588 - "astra_gbfs_223242.pas"
Cohesion: 0.80
Nodes (4): MM(), NetOf(), RectS(), RunFixed()

### Community 589 - "astra_gbg_220655.pas"
Cohesion: 0.80
Nodes (4): MM(), NetOf(), RectS(), RunFixed()

### Community 590 - "astra_gbgm_224135.pas"
Cohesion: 0.80
Nodes (4): MM(), NetOf(), RectS(), RunFixed()

### Community 591 - "astra_gbh_225024.pas"
Cohesion: 0.80
Nodes (4): MM(), NetOf(), RectS(), RunFixed()

### Community 592 - "astra_gbi_225714.pas"
Cohesion: 0.80
Nodes (4): MM(), NetOf(), RectS(), RunFixed()

### Community 593 - "astra_gbj_230930.pas"
Cohesion: 0.80
Nodes (4): MM(), NetOf(), RectS(), RunFixed()

### Community 594 - "astra_move_cl4_T.pas"
Cohesion: 0.80
Nodes (4): FindCap(), PadNet(), RunFixed(), Say()

### Community 595 - "astra_mvcl4_200754.pas"
Cohesion: 0.80
Nodes (4): FindCap(), PadNet(), RunFixed(), Say()

### Community 596 - "astra_tp_gnd_dig_move_scan.py"
Cohesion: 0.70
Nodes (4): describe(), hits(), main(), Tiny BF planning scan: translate only TP_GND_DIG, retaining every track.

### Community 597 - "astra_unsavedbf_222959.pas"
Cohesion: 0.80
Nodes (4): MM(), NetOf(), RectS(), RunFixed()

### Community 598 - "Combined bounded cleanup of all ten BH antenna warnings"
Cohesion: 0.50
Nodes (3): Combined bounded cleanup of all ten BH antenna warnings, Proof and limits, Ten warnings and bounded treatment

### Community 600 - "astra_check_mcu_rx_power_graph.py"
Cohesion: 0.67
Nodes (3): main(), partitions(), Small read-only connectivity check for the final UART partial reroutes.

### Community 601 - "astra_check_mcu_rx_reinforced_graph.py"
Cohesion: 0.67
Nodes (3): main(), partitions(), Small read-only connectivity check for the final UART partial reroutes.

### Community 602 - "astra_check_uart_partial_graph.py"
Cohesion: 0.67
Nodes (3): main(), partitions(), Small read-only connectivity check for the final UART partial reroutes.

### Community 603 - "astra_check_uart_rx1_graph.py"
Cohesion: 0.67
Nodes (3): main(), partitions(), Small read-only connectivity check for the final UART partial reroutes.

### Community 604 - "astra_cl4_feasibility.py"
Cohesion: 0.67
Nodes (3): main(), Offline CL_4 placement feasibility using place_part.py; never edits CAD., records()

### Community 605 - "astra_cs_tx_local_detour.py"
Cohesion: 0.67
Nodes (3): describe(), main(), Small exact local CS detour trials with moved testpad and fixed TX escape.

### Community 607 - "astra_mcu92_inward_seed_check.py"
Cohesion: 0.67
Nodes (3): details(), main(), Small fixed-BF inward MCU92 escape scan; no router or CAD writes.

### Community 608 - "astra_move_gnd_tp_T.pas"
Cohesion: 0.83
Nodes (3): FindPad(), RunFixed(), Say()

### Community 609 - "astra_mvbgm_224135.pas"
Cohesion: 0.83
Nodes (3): FindPad(), RunFixed(), Say()

## Knowledge Gaps
- **803 isolated node(s):** `native_base`, `native_drc`, `seed`, `seed_rows`, `..\\evidence\\GEOMETRY_C2_6L_BF.txt` (+798 more)
  These have ≤1 connection - possible missing edges or undocumented components. (Counts symbols only; 1797 node(s) total have ≤1 connection when file, concept and rationale nodes are included.)
- **133 thin communities (<3 nodes) omitted from report** — run `graphify query` to explore isolated nodes.

## Suggested Questions
_Questions this graph is uniquely positioned to answer:_

- **Why does `EmgScope` connect `EmgScope` to `ReviewWindow`, `emg_plotter.py`, `EmgPlotWidget`, `RecordingController`, `MvcDialog`, `dsp.py`, `EmgFilters`, `AmpNormDialog`, `ProcessingDialog`?**
  _High betweenness centrality (0.002) - this node is a cross-community bridge._
- **Why does `explicit_seed` connect `explicit_seed` to `uartswap_T.pas`, `sx_233624.pas`, `h`, `ASTRA_CH4_LOCAL2_PLANNING_ONLY/MANIFEST.json`?**
  _High betweenness centrality (0.002) - this node is a cross-community bridge._
- **Why does `layer` connect `sx_233624.pas` to `sy_234341.pas`, `s3_000002.pas`, `svc_swap3_T.pas`, `sc_234902.pas`, `explicit_seed`, `svc_swap2_T.pas`?**
  _High betweenness centrality (0.002) - this node is a cross-community bridge._
- **Are the 13 inferred relationships involving `EmgScope` (e.g. with `EmgFilters` and `LeadoffTracker`) actually correct?**
  _`EmgScope` has 13 INFERRED edges - model-reasoned connections that need verification._
- **Are the 4 inferred relationships involving `ReviewWindow` (e.g. with `EmgScope` and `EmgFilters`) actually correct?**
  _`ReviewWindow` has 4 INFERRED edges - model-reasoned connections that need verification._
- **What connects `native_base`, `native_drc`, `seed` to the rest of the system?**
  _803 weakly-connected nodes found - possible documentation gaps or missing edges._
- **Should `EmgScope` be split into smaller, more focused modules?**
  _Cohesion score 0.04750512645249488 - nodes in this community are weakly interconnected._

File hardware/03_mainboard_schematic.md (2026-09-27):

# Main Board — 5-Channel Schematic (net-by-net) + BOM

New wireless main board: 5 active dry-electrode boards (FFC) → 5-channel AFE → STM32U575 ADC →
ST67W611M1-B Wi-Fi, on the power tree in `01_power_tree_design.md`. Analog values confirmed in
`02_afe_signal_chain.md`. Suffix `n = 1..5` = channel number.

---

## A. Per-channel AFE  (replicate ×5)

**A.1 FFC connector `J_Eln` (13-pin, per electrode board)** — pinout mirrors the electrode:
`1 GND · 2 Va_n · 3 GND · 4 Vb_n · 5 GND · 6 Vc_n · 7 GND · 8 VCM_n · 9 GND · 10 3V3_ANA · 11 GND ·
12 VREF · 13 GND`  *(9-pin variant: VREF local on electrode + shared returns — see FFC note.)*

**A.2 Double-differential network → in-amp `U1_n` (AD8237):**
| Net | Via | To |
|---|---|---|
| Va_n | R (100 k) | IN+ node `DDp_n` |
| Vc_n | R (100 k) | IN+ node `DDp_n` → U1_n **IN+** |
| Vb_n | R (50 k) | U1_n **IN−** |
| U1_n REF | — | `Vservo_n` (from A.3) |
| U1_n FB / gain | R2H 26.1 k (OUT→FB), R1 1.07 k (FB→VRf), **CH 12 nF ‖ R2H** | G = 25.4, LPF 508 Hz |
| U1_n +VS / −VS | 3V3_ANA / GND | 100 nF + 1 µF decoupling |
| U1_n OUT | — | `INA_OUT_n` |

**A.3 DC servo `U9_n` (one AD8648 amp, inverting integrator):**
`INA_OUT_n → R22 (2 MΩ) → U9_n IN−` ; `C3 (0.1 µF*) : U9_n OUT→IN−` ; `U9_n IN+ = VRf` ;
`U9_n OUT = Vservo_n → U1_n REF`.  *(*0.1 µF → 0.8 Hz for ~1 s artifact recovery; 3.3 µF = original 0.024 Hz.)*

**A.4 Interstage HPF + gain `U3_n` (one AD8648 amp, inverting ×8):**
`INA_OUT_n → CL (0.82 µF) → RL (10 k) → U3_n IN−` (HPF 19.4 Hz) ; `RG (80.6 k) : OUT→IN−` (gain −8.06) ;
`U3_n IN+ = VRf` ; `U3_n OUT = VOUT_n → STM32 ADC`.  **Total gain ≈ 205, centered on 1.65 V.**

---

## B. Shared analog blocks (once for all 5 channels) — **DRL-free, see `02` decision**

**B.1 VREF generation:** `3V3_ANA → R(100 k) → VDiv ← R(100 k) → GND`, with **100 nF + 10 µF at VDiv**
(big cap is fine here — it is an *input* node, not an op-amp output) = **1.65 V**.

**B.2 TWO VREF buffers** (unity-gain, `+`=VDiv, `−`=own output; **100 nF only** on each output, no bulk cap):
- **VRf_A** → channels 1–3 (their R1, servo `+`, gain-stage `+`).
- **VRf_B** → channels 4–5 + **FFC pin 12** of all 5 electrode boards.
Splitting the load reduces shared-impedance coupling between channels.

**B.3 Reference electrode (replaces the DRL):** `J_REF pad → R_ref (10 kΩ default; 0 Ω = tested config)
→ GND`. **One** reference electrode serves all 5 channels. Keep an **unpopulated DRL footprint + a
GND↔DRL solder jumper** on this net as a future option (no VCM hardware needed — Va/Vb/Vc are already here).

**B.4 Op-amp packing (perfect fit, nothing idle):** 5× AD8237 (U1_1..5) + **3× quads = 12 amps** =
5 gain + 5 servo + 2 VREF buffers. Recommended quad = **MCP6404** (micropower) or AD8648.
| Chip | A | B | C | D |
|---|---|---|---|---|
| U2 | ch1 gain | ch1 servo | **VREF buf A** | **VREF buf B** |
| U3 | ch2 gain | ch2 servo | ch3 gain | ch3 servo |
| U4 | ch4 gain | ch4 servo | ch5 gain | ch5 servo |
*(U2 C/D live on the `Analog_Shared` sheet — use Altium multi-part placement.)*

---

## C. STM32U575AII6Q  (ADC + host; set exact pins in CubeMX)

| Function | Peripheral / pins (suggested) | Notes |
|---|---|---|
| EMG in ×5 | ADC1: EMG1–4 = PA0–PA3 (ADC1_IN5–IN8), **EMG5 = PC4 (ADC1_IN13)** | VOUT_1..5; DMA, ~1–2 kS/s/ch, 14-bit. EMG5 moved PA4 (IN9) → PC4 (IN13) on 2026-09-27 for C2 PCB routing (LQFP100 pin 29 → 33; same ADC1). Firmware scan list: IN5, IN6, IN7, IN8, IN13 |
| VBAT sense | ADC1_IN on PA5 | from fuel-gauge node or divider |
| USB detect | GPIO PB2 | VBUS-sense → disable acquisition on USB |
| SPI→ST67 | SPI1: SCK PA5→(use PB3), MISO PB4, MOSI PB5, CS PA15 | ≤40 MHz full-duplex |
| ST67 ctrl | CHIP_EN PB1, SPI_RDY PB0 (EXTI), BOOT PB10 | CHIP_EN high ≥3.3 ms after ST67 power |
| UART↔ST67 | **USART1: TX = PB6, RX = PB7** (AF7) | Moved from PA9/PA10 (LQFP100 pins 68/69) to PB6/PB7 (pins 92/93) on 2026-09-27 for C2 PCB routing - same USART1, only the pin mux changes. PA9/PA10 (system-bootloader UART) are now unused; program via SWD (Tag-Connect). |
| I²C→gauge | I2C1: SCL PB8, SDA PB9 | MAX17048 @0x36; ALRT→PB6 |
| Clock | HSE 16–32 MHz (or HSI); **LSE 32.768 kHz** | LSE can also feed ST67 32 kHz |
| SWD | SWDIO PA13, SWCLK PA14, NRST | 5 test pads |
| Power | VDD/VDDIO = 3V3_DIG; **VDDA/VREF+ = 3V3_ANA** | 100 nF/pin + 4.7 µF bulk; VDDA 1 µF+100 nF |

> ADC references the **quiet 3V3_ANA** (VDDA/VREF+), same rail as the electrodes ⇒ ratiometric, low-noise.

---

## D. ST67W611M1-B  (Wi-Fi/BLE module; pins per ST datasheet / B2413 ref)

| Function | Pin(s) | Connection |
|---|---|---|
| Power | VDD33 (16), VDDIO (9, 25) | 3V3_DIG; **10 µF each pin, own via** |
| Ground | GND (10,15,18,26,30,32) + center pad | solid plane; **≥5 vias in center pad** |
| Enable | CHIP_EN | STM32 GPIO + **100 nF to GND**; high ≥3.3 ms after power |
| SPI (host) | CLK, MOSI, MISO, CS, SPI_RDY | to STM32 SPI1 (≤40 MHz) |
| Boot/test | UART_TX (22), UART_RX (23), BOOT | 3 test pads (factory FW / recovery) |
| 32 kHz | 32K_IN | optional from STM32 LSE (3.3 V swing) or use internal osc |
| Antenna | on-module PCB antenna (-B) | **all-layer keep-out, board corner** (see 04) |

---

## E. Connectors

| Ref | Type | Purpose |
|---|---|---|
| J_El1..5 | 13-pin (or 9) FFC, 0.5 mm | 5 electrode boards |
| J_DRL | 1-pin pad / snap | shared DRL reference electrode on body |
| J_USB | USB-C 16-pin | charge + optional DFU (power tree §1) |
| J_BAT | JST-PH 2-pin | Li-Po (power tree §3) |
| TP_SWD | 5 pads | SWDIO/SWCLK/NRST/3V3/GND |
| TP_ST67 | 3 pads | UART_TX/RX/BOOT |

---

## F. Consolidated BOM (main board)

| Qty | Ref | Part | Pkg |
|---|---|---|---|
| 1 | U_MCU | STM32U575AII6Q | UFBGA-169 |
| 1 | U_RF | ST67W611M1-B | module |
| 5 | U1_1..5 | AD8237ARMZ | MSOP-8 |
| 3 | U2_A..C | AD8648ARUZ *(or MCP6404/TLV9064)* | TSSOP-14 |
| 1 | U_CHG | MCP73831T-2ACI/OT | SOT-23-5 |
| 1 | U_MUX | TPS2116DMWR | VSSOP-8 |
| 1 | U_BB | TPS631000DRLR | SOT-583 |
| 1 | U_LDO | TPS7A2033PDBVR | SOT-23-5 |
| 1 | U_FG | MAX17048G+T10 | µDFN-8 |
| 1 | Q_RP | DMG3415U | SOT-23 |
| 1 | L_BB | 1 µH shielded [confirm DS] | 2016 |
| 5 | — | FFC 13-pin 0.5 mm (Hirose TF31 class) | — |
| — | R (per ch ×5) | 100 k×2, 50 k, 26.1 k, 1.07 k, 2 M, 10 k, 80.6 k | 0402 |
| — | R (shared) | 100 k×2 (VREF), 50 k×5 + 10 k + 1 M (DRL) | 0402 |
| — | C (per ch ×5) | 12 nF, 0.1 µF (servo), 0.82 µF, +decoupling | 0402 |
| — | C/R (digital) | ST67 10 µF×3, 100 nF×many, 4.7 µF bulk, I²C 4.7 k×2 | 0402/0805 |
| — | Power passives | per `01_power_tree_design.md` | — |

---

## G. Verify
- Per channel: DC at every node ≈ 1.65 V; VOUT swings ±≤1.65 V, no clip at MVC.
- Servo holds baseline at 1.65 V; recovers <2 s after a forced saturation.
- DRL: 50/60 Hz residual drops with DRL connected (tune R_in/R_f).
- ADC: 5 channels stream cleanly into the emg-saw scope; VDDA = 3V3_ANA quiet.
- ST67: CHIP_EN timing, SPI enumerates, Wi-Fi associates; antenna keep-out clean.

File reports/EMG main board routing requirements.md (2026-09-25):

# Unbroken Planes and Tight Loops Govern Routing

Judge this board's routed copper on four things above all. L2 must be unbroken, and so must L4 under every L3 trace. Every switching and decoupling loop must close on L1 in the order pin → capacitor pad → via. The ST67W611M1 antenna zone must be free of copper on all four layers. And the board must be ordered as the exact JLC04121H-3313 stack-up with a copper-to-edge setback of at least 0.4–0.5 mm. The part makers give almost no numeric routing distances. TI, ADI, ST, Microchip and Murata give no minimum spacing between the switcher and the analog circuits, no limit on LX copper, and no trace widths for these parts. The firm numbers come from three places instead:

- **Component limits.** Examples are the TPS631000 low-side FB resistor ≤ 100 kΩ, VCAP ESR < 20 mΩ at 3 MHz, and TPS7A2030 COUT of 1–200 µF.
- **Land patterns.** Examples are the BK13C's 0.18 mm pads at 0.35 mm pitch and the ST67's 5 mm antenna portion.
- **Fabricator limits.** Examples are 0.09/0.09 mm track and space, and 0.4 mm copper-to-V-cut.

Three fabrication items outrank any single trace:

- **The stack-up must be named on the order.** JLC's default 1.2 mm stack is JLC04121H-7628. If that is built, a 0.161 mm line on L1 designed for 50 Ω comes out at about 71.5 Ω.
- **The 0.254 mm edge rule fails panel assembly.** The 0.35 mm-pitch connectors need Standard PCBA, and on a board only 45 mm wide that means a panel. A V-cut panel needs 0.4 mm copper-to-edge, which the exported rule fails.
- **Exposed-pad vias need a written decision.** The vias under the BQ24072T and the ST67 need a documented fill, tent or paste treatment.
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

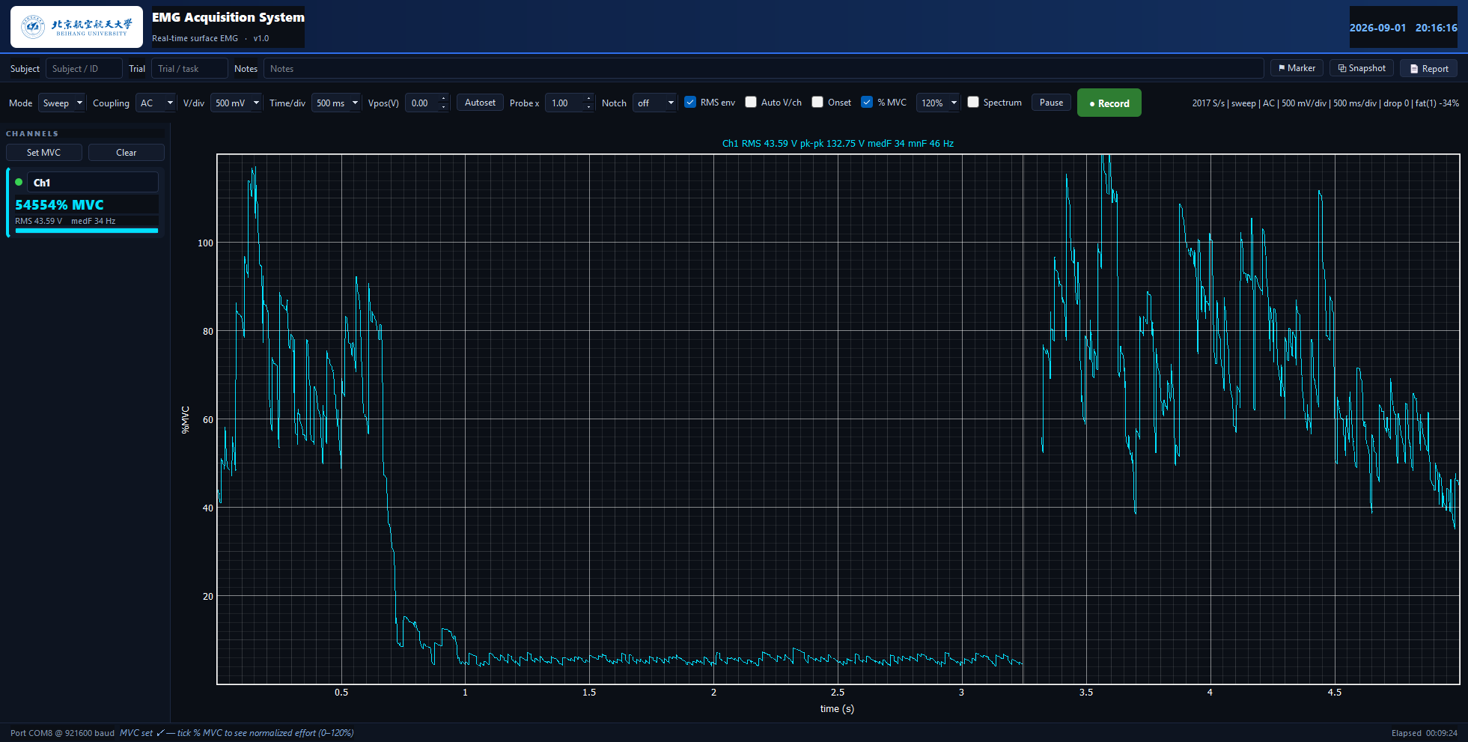
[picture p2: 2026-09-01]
emg_report_20260901_201617.png

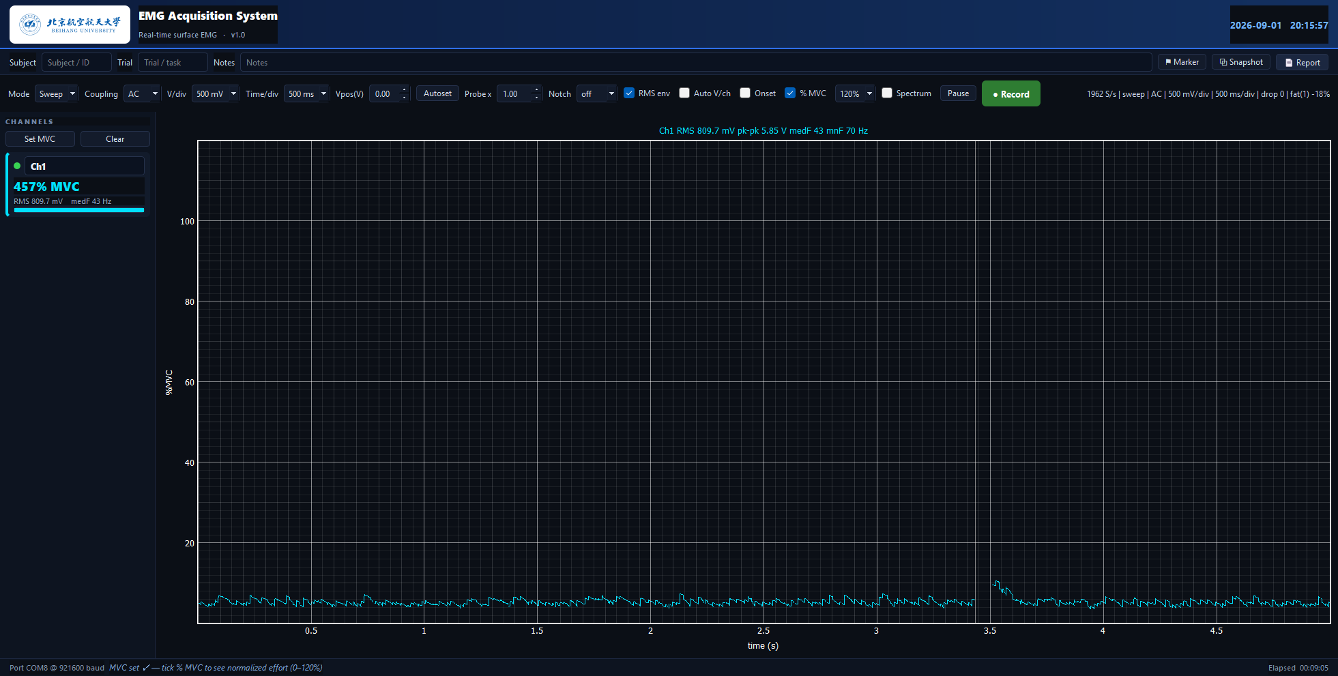
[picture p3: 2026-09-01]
emg_report_20260901_201557.png

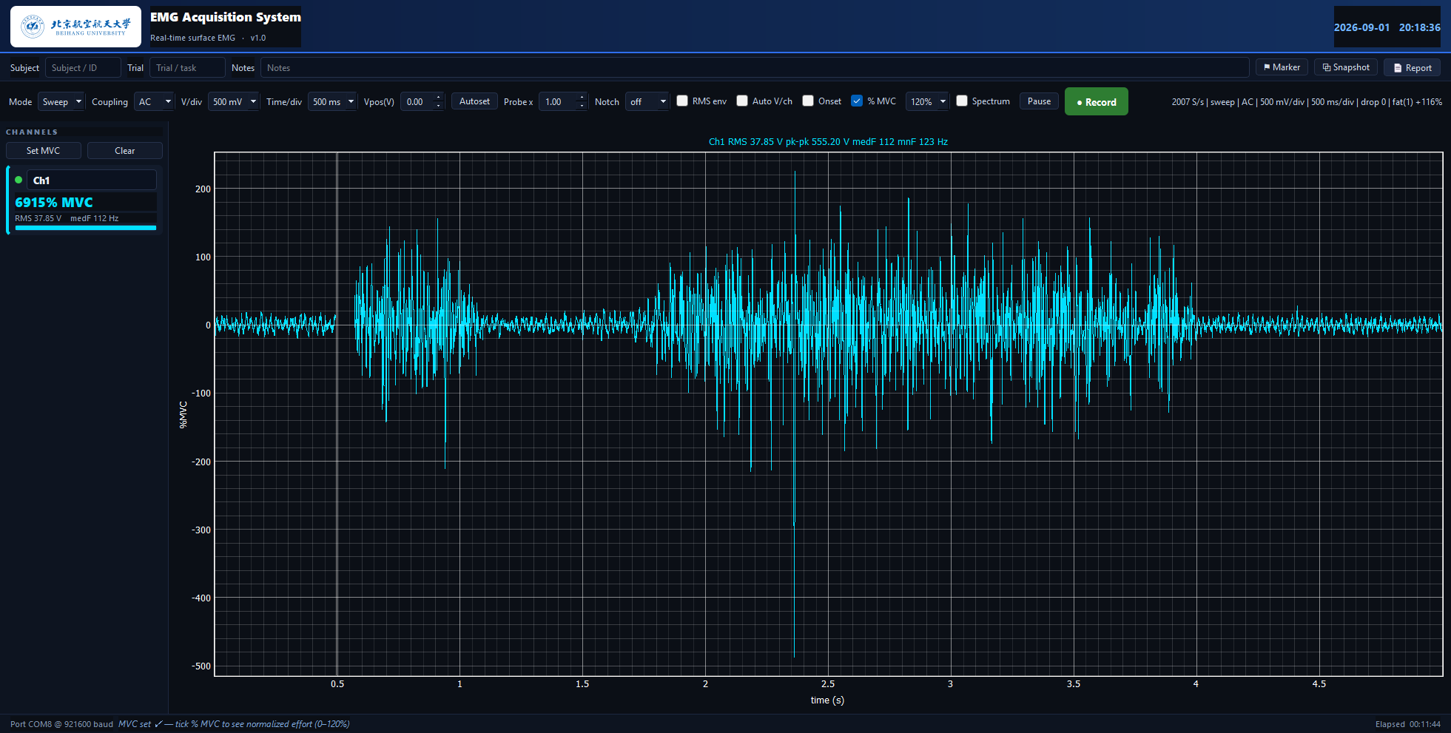
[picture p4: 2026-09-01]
emg_report_20260901_201837.png

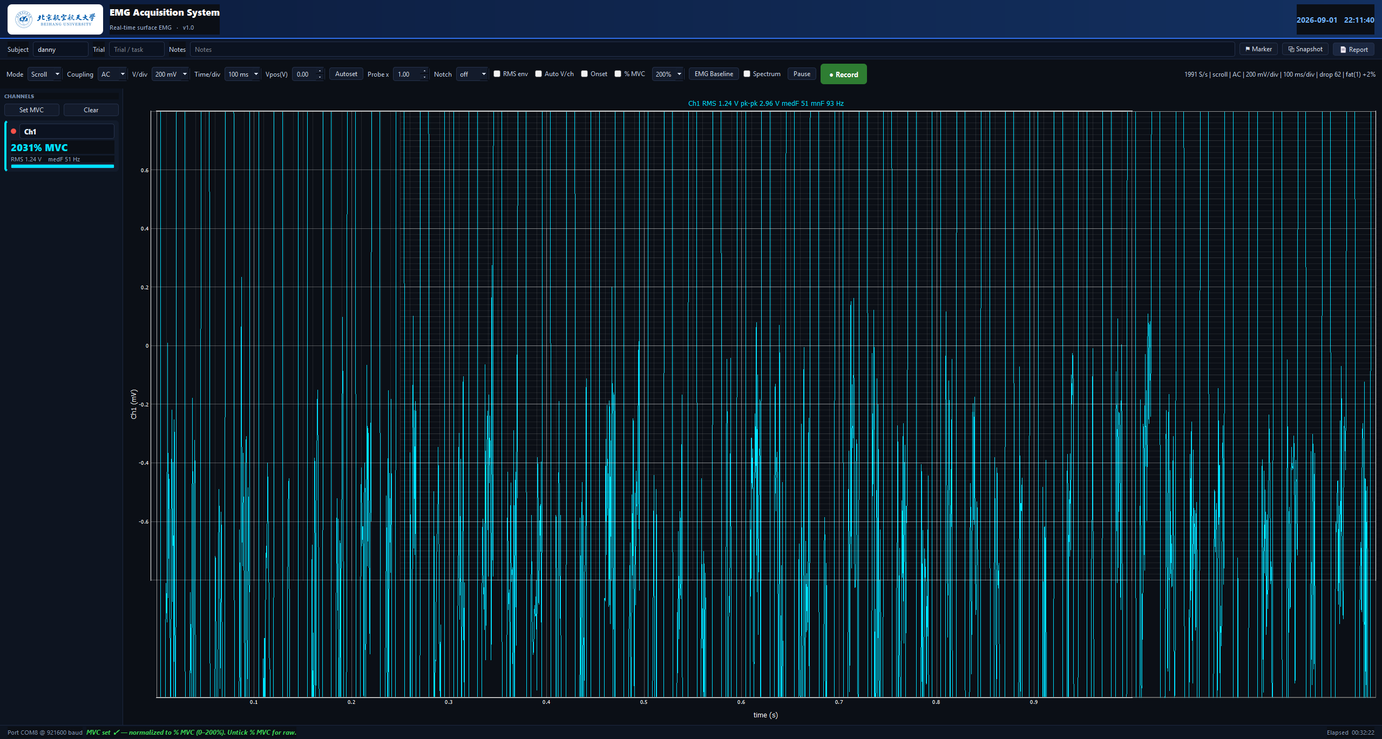
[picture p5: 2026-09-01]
emg_report_20260901_221140.png

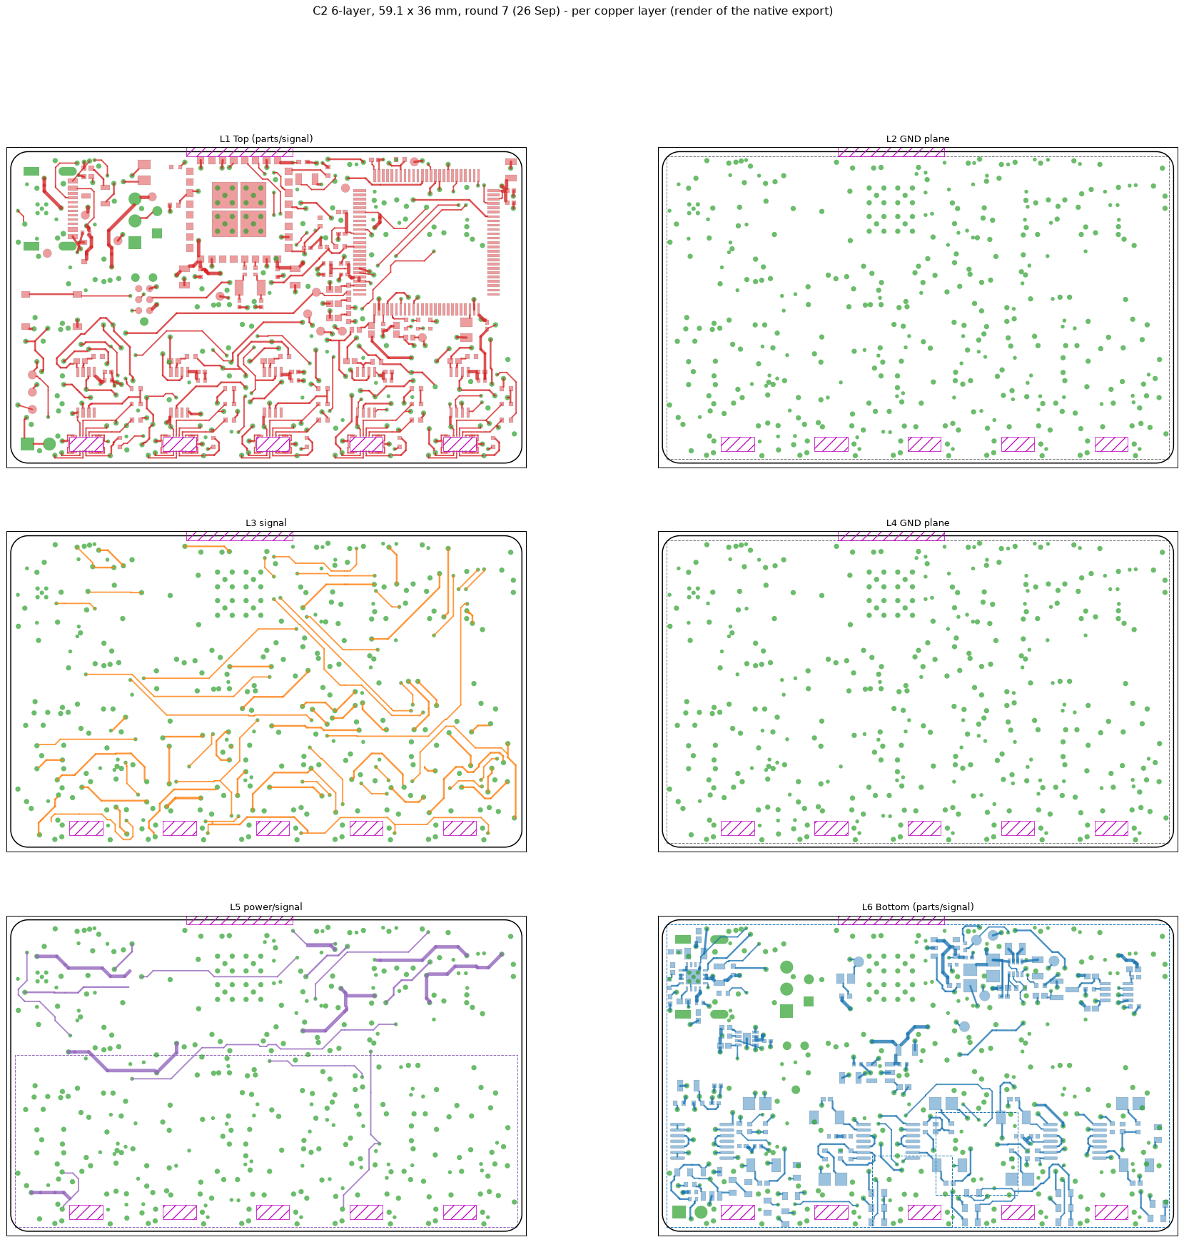
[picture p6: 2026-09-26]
hardware/compact_mainboard_20260925T115919Z/evidence/views/C2_6L_ROUTED_M_layers.png

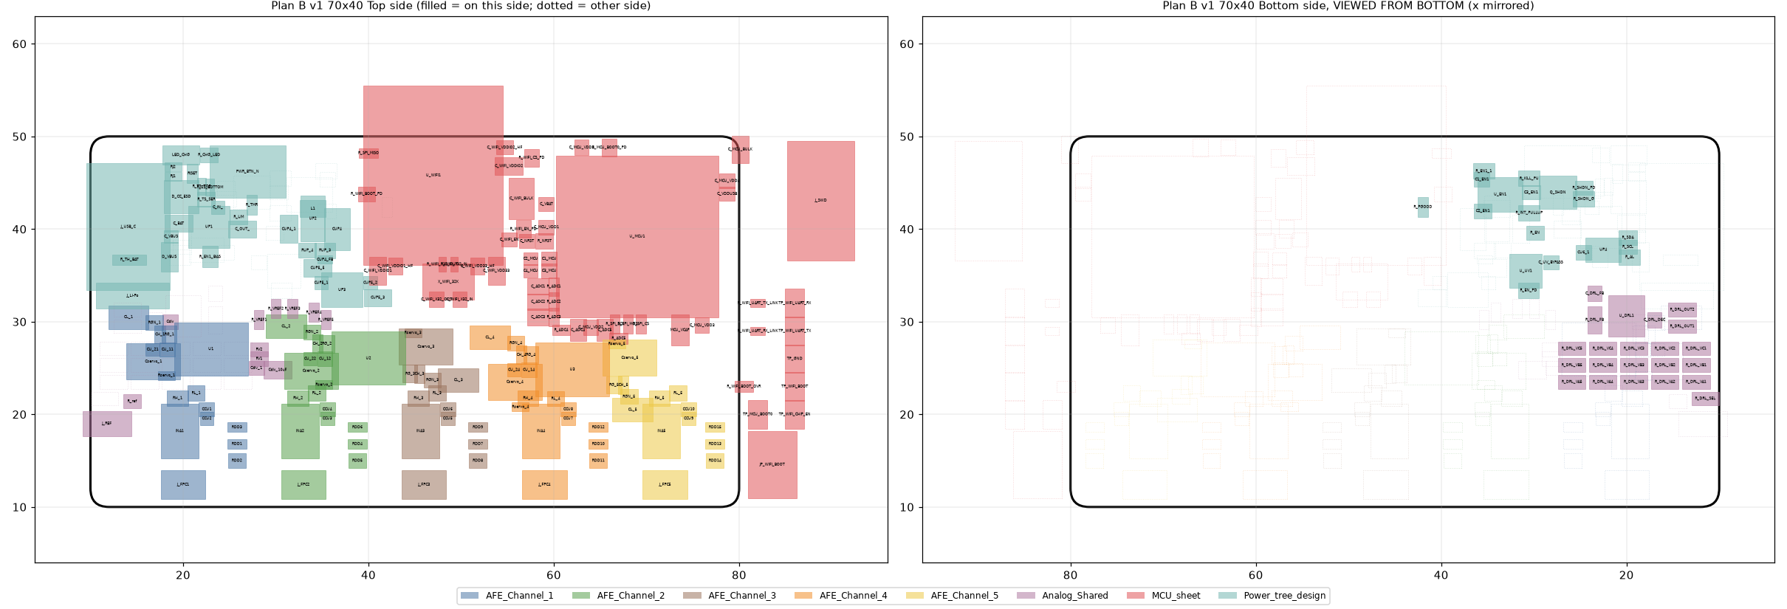
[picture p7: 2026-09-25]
hardware/compact_mainboard_20260925T115919Z/evidence/PLAN_B_v1.png

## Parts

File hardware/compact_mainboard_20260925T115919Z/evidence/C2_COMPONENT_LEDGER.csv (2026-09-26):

designator | src_uid | group | sheet | b_side | b_x | b_y | b_rot | c2_side | c2_x | c2_y | c2_rot | side_changed | footprint | footprint_changed | height_mm | reason
C1_EN1 | \KWJFQQPD | PB_CTRL | Power_tree_design | Bottom | 75.6099 | 43.35 | 180.0 | Bottom | 64.6899 | 39.35 | 180.0 |  | FP-GRM155-0_05-IPC_C |  | 0.552 | pushbutton controller (Bottom) under the STM32, rigid with it
C1_MCU | \KNSGXSGY | MCU | MCU_sheet | Top | 59.5 | 37.1 | 180.0 | Top | 48.58 | 33.1 | 180.0 |  | FP-GRM155-0_05-IPC_C |  | 0.254 | STM32 block: B local layout incl. ADC/VCAP/bypass, rigid translation
C2_EN1 | \AUBOOCXZ | PB_CTRL | Power_tree_design | Bottom | 75.51 | 39.95 | 0.0 | Bottom | 64.59 | 35.95 | 0.0 |  | FP-CC0402-MFG |  | 0.55 | pushbutton controller (Bottom) under the STM32, rigid with it
C2_MCU | \TSGCAGJY | MCU | MCU_sheet | Top | 57.5 | 37.1 | 0.0 | Top | 46.58 | 33.1 | 0.0 |  | *MURATA_GRM155C71C105KE11D_0 |  | 0.6 | STM32 block: B local layout incl. ADC/VCAP/bypass, rigid translation
C3_EN1 | \BRZQATAL | PB_CTRL | Power_tree_design | Bottom | 70.31 | 41.95 | 0.0 | Bottom | 59.39 | 37.95 | 0.0 |  | FP-CC0402-MFG |  | 0.55 | pushbutton controller (Bottom) under the STM32, rigid with it
C3_MCU | \TDOPZFWR | MCU | MCU_sheet | Top | 59.5 | 35.8 | 180.0 | Top | 48.58 | 31.8 | 180.0 |  | FP-GRM155-0_05-IPC_C |  | 0.254 | STM32 block: B local layout incl. ADC/VCAP/bypass, rigid translation
C4_MCU | \WPXKGRZF | MCU | MCU_sheet | Top | 57.5 | 35.8 | 0.0 | Top | 46.58 | 31.8 | 0.0 |  | *MURATA_GRM155C71C105KE11D_0 |  | 0.6 | STM32 block: B local layout incl. ADC/VCAP/bypass, rigid translation
CCU1 | \DPDOLLAJ | AFE | AFE_Channel_1 | Top | 22.55 | 20.55 | 0.0 | Top | 21.25 | 20.55 | 0.0 |  | FP-GRM155-0_05-IPC_C |  | 0.254 | channel input stage: B template translated to the 10.8 mm BK13 pitch (Top, unchanged internally)
CCU10 | \PGDJRIFP | AFE | AFE_Channel_5 | Top | 74.55 | 20.55 | 0.0 | Top | 64.45 | 20.55 | 0.0 |  | FP-GRM155-0_05-IPC_C |  | 0.254 | channel input stage: B template translated to the 10.8 mm BK13 pitch (Top, unchanged internally)
CCU2 | \MFMCRQQU | AFE | AFE_Channel_1 | Top | 22.55 | 19.55 | 180.0 | Top | 21.25 | 19.55 | 180.0 |  | *MURATA_GRM155C71C105KE11D_0 |  | 0.6 | channel input stage: B template translated to the 10.8 mm BK13 pitch (Top, unchanged internally)
CCU3 | \CIMHMRWX | AFE | AFE_Channel_2 | Top | 35.55 | 19.55 | 180.0 | Top | 32.05 | 19.55 | 180.0 |  | *MURATA_GRM155C71C105KE11D_0 |  | 0.6 | channel input stage: B template translated to the 10.8 mm BK13 pitch (Top, unchanged internally)
CCU4 | \PJWUZVFE | AFE | AFE_Channel_2 | Top | 35.55 | 20.55 | 0.0 | Top | 32.05 | 20.55 | 0.0 |  | FP-GRM155-0_05-IPC_C |  | 0.254 | channel input stage: B template translated to the 10.8 mm BK13 pitch (Top, unchanged internally)
CCU5 | \PYTUSSRE | AFE | AFE_Channel_3 | Top | 48.55 | 19.55 | 180.0 | Top | 42.85 | 19.55 | 180.0 |  | *MURATA_GRM155C71C105KE11D_0 |  | 0.6 | channel input stage: B template translated to the 10.8 mm BK13 pitch (Top, unchanged internally)
CCU6 | \EIDXTRHR | AFE | AFE_Channel_3 | Top | 48.55 | 20.55 | 0.0 | Top | 42.85 | 20.55 | 0.0 |  | FP-GRM155-0_05-IPC_C |  | 0.254 | channel input stage: B template translated to the 10.8 mm BK13 pitch (Top, unchanged internally)
CCU7 | \KKLEFVPX | AFE | AFE_Channel_4 | Top | 61.55 | 19.55 | 180.0 | Top | 53.65 | 19.55 | 180.0 |  | *MURATA_GRM155C71C105KE11D_0 |  | 0.6 | channel input stage: B template translated to the 10.8 mm BK13 pitch (Top, unchanged internally)
CCU8 | \XTYCAQJK | AFE | AFE_Channel_4 | Top | 61.55 | 20.55 | 0.0 | Top | 53.65 | 20.55 | 0.0 |  | FP-GRM155-0_05-IPC_C |  | 0.254 | channel input stage: B template translated to the 10.8 mm BK13 pitch (Top, unchanged internally)
CCU9 | \MBHOTVHO | AFE | AFE_Channel_5 | Top | 74.55 | 19.55 | 180.0 | Top | 64.45 | 19.55 | 180.0 |  | *MURATA_GRM155C71C105KE11D_0 |  | 0.6 | channel input stage: B template translated to the 10.8 mm BK13 pitch (Top, unchanged internally)
CH_1 | \MIJCOZNW | AFE | AFE_Channel_1 | Top | 17.5 | 28.625 | 270.0 | Bottom | 20.1 | 21.95 | 270.0 | Y | CAPC1005X55N |  | 0.55 | op-amp package-aware group on Bottom directly under its channels (servo/post-amp at their pins)
CH_2 | \VTQJFIQM | AFE | AFE_Channel_2 | Top | 34.5 | 27.625 | 270.0 | Bottom | 30.6 | 18.85 | 270.0 | Y | CAPC1005X55N |  | 0.55 | op-amp package-aware group on Bottom directly under its channels (servo/post-amp at their pins)
CH_3 | \BHEIABIF | AFE | AFE_Channel_3 | Top | 45.5 | 24.375 | 90.0 | Bottom | 41.6 | 21.95 | 270.0 | Y | CAPC1005X55N |  | 0.55 | op-amp package-aware group on Bottom directly under its channels (servo/post-amp at their pins)
CH_4 | \VBHITULI | AFE | AFE_Channel_4 | Top | 56.5 | 26.425 | 270.0 | Bottom | 52.2 | 18.85 | 270.0 | Y | CAPC1005X55N |  | 0.55 | op-amp package-aware group on Bottom directly under its channels (servo/post-amp at their pins)
CH_5 | \SDBPLGOM | AFE | AFE_Channel_5 | Top | 67.5 | 23.175 | 90.0 | Bottom | 63.2 | 21.95 | 270.0 | Y | CAPC1005X55N |  | 0.55 | op-amp package-aware group on Bottom directly under its channels (servo/post-amp at their pins)
CL_1 | \GNLAPLDE | AFE | AFE_Channel_1 | Top | 14.1 | 30.5 | 0.0 | Bottom | 21.0 | 24.75 | 0.0 | Y | CAPC2013X135X45ML10T25 |  | 1.35 | op-amp package-aware group on Bottom directly under its channels (servo/post-amp at their pins)
CL_2 | \WSSOZXTJ | AFE | AFE_Channel_2 | Top | 31.1 | 29.5 | 0.0 | Bottom | 29.7 | 16.05 | 180.0 | Y | CAPC2013X135X45ML10T25 |  | 1.35 | op-amp package-aware group on Bottom directly under its channels (servo/post-amp at their pins)
CL_3 | \TMGHLPAL | AFE | AFE_Channel_3 | Top | 49.7 | 23.7 | 180.0 | Bottom | 42.5 | 24.75 | 0.0 | Y | CAPC2013X135X45ML10T25 |  | 1.35 | op-amp package-aware group on Bottom directly under its channels (servo/post-amp at their pins)
CL_4 | \KJVBWSRF | AFE | AFE_Channel_4 | Top | 53.1 | 28.3 | 0.0 | Bottom | 51.3 | 16.05 | 180.0 | Y | CAPC2013X135X45ML10T25 |  | 1.35 | op-amp package-aware group on Bottom directly under its channels (servo/post-amp at their pins)
CL_5 | \YBRHADYL | AFE | AFE_Channel_5 | Top | 68.5 | 20.5 | 180.0 | Bottom | 64.1 | 24.75 | 0.0 | Y | CAPC2013X135X45ML10T25 |  | 1.35 | op-amp package-aware group on Bottom directly under its channels (servo/post-amp at their pins)
CU6_1 | \UFCUTPNQ | GAUGE | Power_tree_design | Bottom | 24.66 | 35.975 | 180.0 | Bottom | 22.16 | 31.975 | 180.0 |  | FP-GRM155-0_05-IPC_C |  | 0.552 | fuel gauge (Bottom) near the battery header
CUP4 | \TDBSYUJF | CONVERTER | Power_tree_design | Top | 36.6 | 40.75 | 270.0 | Bottom | 48.2119 | 40.4335 | 270.0 | Y | FP-GRM219-0_2-0_1-IPC_A |  | 0.953 | TPS631000 cell flipped whole (B hot loop) under the STM32, clear of ST67 vias/crystal/antenna/ADC corner
CUP4_1 | \OCTWYPFX | CONVERTER | Power_tree_design | Top | 31.4 | 40.75 | 270.0 | Bottom | 53.4119 | 40.4335 | 270.0 | Y | FP-GCM21B-0_2-e0_2_0_7-MFG |  | 1.451 | TPS631000 cell flipped whole (B hot loop) under the STM32, clear of ST67 vias/crystal/antenna/ADC corner
CUP4_FB | \XDRNRJCW | CONVERTER | Power_tree_design | Top | 35.3 | 37.45 | 0.0 | Bottom | 49.5119 | 37.1335 | 180.0 | Y | CAPC1005X55X25LL05T10 |  | 0.55 | TPS631000 cell flipped whole (B hot loop) under the STM32, clear of ST67 vias/crystal/antenna/ADC corner
CUP5_1 | \KRWEPBDB | LDO | Power_tree_design | Top | 33.9 | 34.6 | 180.0 | Bottom | 37.85 | 29.3375 | 0.0 | Y | *MURATA_GRM155C71C105KE11D_0 |  | 0.6 | TPS7A2030 cell flipped whole to the power/analog boundary
CUP5_2 | \ALYAKZJE | LDO | Power_tree_design | Top | 39.2 | 34.6 | 180.0 | Bottom | 32.55 | 29.3375 | 0.0 | Y | *MURATA_GRM155C71C105KE11D_0 |  | 0.6 | TPS7A2030 cell flipped whole to the power/analog boundary
CUP5_3 | \GUCDCQUU | LDO | Power_tree_design | Top | 40.0 | 33.0 | 180.0 | Bottom | 31.75 | 27.7375 | 0.0 | Y | FP-GCM21B-0_2-e0_2_0_7-MFG |  | 1.451 | TPS7A2030 cell flipped whole to the power/analog boundary
CUP5_5 | \ZEQWUVAB | LDO | Power_tree_design | Top | 33.5 | 36.2 | 180.0 | Bottom | 38.25 | 30.9375 | 0.0 | Y | FP-GCM21B-0_2-e0_2_0_7-MFG |  | 1.451 | TPS7A2030 cell flipped whole to the power/analog boundary
CU_11 | \QTDZGZYC | AFE | AFE_Channel_1 | Top | 18.3 | 27.0 | 0.0 | Bottom | 19.3 | 19.85 | 0.0 | Y | FP-GRM155-0_05-IPC_C |  | 0.552 | op-amp package-aware group on Bottom directly under its channels (servo/post-amp at their pins)
CU_12 | \KZHXEMRX | AFE | AFE_Channel_2 | Top | 35.3 | 26.0 | 0.0 | Bottom | 31.4 | 20.95 | 180.0 | Y | FP-GRM155-0_05-IPC_C |  | 0.552 | op-amp package-aware group on Bottom directly under its channels (servo/post-amp at their pins)
CU_14 | \HFAFTJTT | AFE | AFE_Channel_4 | Top | 57.3 | 24.8 | 0.0 | Bottom | 53.0 | 20.95 | 180.0 | Y | FP-GRM155-0_05-IPC_C |  | 0.552 | op-amp package-aware group on Bottom directly under its channels (servo/post-amp at their pins)
CU_21 | \HBLBLIXO | AFE | AFE_Channel_1 | Top | 16.7 | 27.0 | 180.0 | Bottom | 21.05 | 19.85 | 0.0 | Y | *MURATA_GRM155C71C105KE11D_0 |  | 0.6 | op-amp package-aware group on Bottom directly under its channels (servo/post-amp at their pins)
CU_22 | \QFBGIYQT | AFE | AFE_Channel_2 | Top | 33.7 | 26.0 | 180.0 | Bottom | 29.65 | 20.95 | 180.0 | Y | *MURATA_GRM155C71C105KE11D_0 |  | 0.6 | op-amp package-aware group on Bottom directly under its channels (servo/post-amp at their pins)
CU_24 | \PSMZMIOA | AFE | AFE_Channel_4 | Top | 55.7 | 24.8 | 180.0 | Bottom | 51.25 | 20.95 | 180.0 | Y | *MURATA_GRM155C71C105KE11D_0 |  | 0.6 | op-amp package-aware group on Bottom directly under its channels (servo/post-amp at their pins)
C_ADC1 | \CWYZJILP | ADC_RC | MCU_sheet | Top | 58.3 | 34.1 | 180.0 | Top | 47.38 | 30.1 | 180.0 |  | FP-GRM155-0_15-IPC_A |  | 0.254 | ADC RC networks: rigid with the STM32 block
C_ADC2 | \ECVYCTDZ | ADC_RC | MCU_sheet | Top | 58.3 | 32.45 | 180.0 | Top | 47.38 | 28.45 | 180.0 |  | FP-GRM155-0_15-IPC_A |  | 0.254 | ADC RC networks: rigid with the STM32 block
C_ADC3 | \CNHMIMHQ | ADC_RC | MCU_sheet | Top | 58.3 | 30.8 | 180.0 | Top | 47.38 | 26.8 | 180.0 |  | FP-GRM155-0_15-IPC_A |  | 0.254 | ADC RC networks: rigid with the STM32 block
C_ADC4 | \IWHUAAYK | ADC_RC | MCU_sheet | Top | 62.6 | 29.4 | 270.0 | Top | 51.68 | 25.4 | 270.0 |  | FP-GRM155-0_15-IPC_A |  | 0.254 | ADC RC networks: rigid with the STM32 block
C_ADC5 | \BBGOTLNQ | ADC_RC | MCU_sheet | Top | 65.5 | 29.4 | 90.0 | Top | 54.58 | 25.4 | 90.0 |  | FP-GRM155-0_15-IPC_A |  | 0.254 | ADC RC networks: rigid with the STM32 block
C_BAT | \IENRODLZ | CHARGER | Power_tree_design | Top | 19.5 | 42.0 | 180.0 | Bottom | 13.8832 | 42.0793 | 0.0 | Y | FP-GCM21B-0_2-e0_2_0_7-MFG |  | 1.451 | charger cell on Bottom; UP1 exposed-pad vias under the grounded USB-C shell
C_DRL_DEC | \EDUIKKDR | AFE | Analog_Shared | Bottom | 17.0 | 30.2 | 90.0 | Bottom | 13.5058 | 14.528 | 0.0 |  | EMG_DRL_C0402 |  | 0.552 | DNP DRL provision kept physically, Bottom under the sockets / J_REF
C_DRL_FB | \XCYGPLDA | AFE | Analog_Shared | Bottom | 23.45 | 33.05 | 90.0 | Bottom | 13.5423 | 13.6759 | 0.0 |  | EMG_DRL_C0402 |  | 0.552 | DNP DRL provision kept physically, Bottom under the sockets / J_REF
C_IN_ | \ZMESUDIN | CHARGER | Power_tree_design | Top | 23.75 | 43.75 | 180.0 | Bottom | 14.35 | 36.4 | 0.0 | Y | *MURATA_GRM155C71C105KE11D_0 |  | 0.6 | charger cell on Bottom; UP1 exposed-pad vias under the grounded USB-C shell
C_MCU_BULK | \XNGEFMHP | MCU | MCU_sheet | Top | 78.75 | 47.9 | 90.0 | Top | 67.83 | 43.9 | 90.0 |  | FP-GCM21B-0_2-e0_2_0_7-MFG |  | 0.254 | STM32 block: B local layout incl. ADC/VCAP/bypass, rigid translation
C_MCU_VDD1 | \QBPNORLY | MCU | MCU_sheet | Top | 59.2 | 40.5 | 0.0 | Top | 48.28 | 36.5 | 0.0 |  | FP-GRM155-0_05-IPC_C |  | 0.254 | STM32 block: B local layout incl. ADC/VCAP/bypass, rigid translation
C_MCU_VDD2 | \BIEOJUNV | MCU | MCU_sheet | Top | 64.0 | 29.7 | 90.0 | Top | 53.08 | 25.7 | 90.0 |  | FP-GRM155-0_05-IPC_C |  | 0.254 | STM32 block: B local layout incl. ADC/VCAP/bypass, rigid translation
C_MCU_VDD3 | \AUVFQSTI | MCU | MCU_sheet | Top | 76.0 | 29.9 | 90.0 | Top | 65.08 | 25.9 | 90.0 |  | FP-GRM155-0_05-IPC_C |  | 0.254 | STM32 block: B local layout incl. ADC/VCAP/bypass, rigid translation
C_MCU_VDD4 | \ABSRTBCD | MCU | MCU_sheet | Top | 78.7 | 45.5 | 0.0 | Top | 67.78 | 41.5 | 0.0 |  | FP-GRM155-0_05-IPC_C |  | 0.254 | STM32 block: B local layout incl. ADC/VCAP/bypass, rigid translation
C_MCU_VDD5 | \OOSRRHMX | MCU | MCU_sheet | Top | 63.0 | 49.03 | 0.0 | Top | 52.08 | 45.03 | 0.0 |  | FP-GRM155-0_05-IPC_C |  | 0.254 | STM32 block: B local layout incl. ADC/VCAP/bypass, rigid translation
C_NRST | \UTOMCBIX | MCU | MCU_sheet | Top | 57.1 | 39.0 | 180.0 | Top | 46.18 | 35.0 | 180.0 |  | FP-GRM155-0_05-IPC_C |  | 0.254 | STM32 block: B local layout incl. ADC/VCAP/bypass, rigid translation
C_OUT_ | \PIABGTTK | CHARGER | Power_tree_design | Top | 26.4 | 41.4 | 0.0 | Bottom | 16.6 | 39.65 | 90.0 | Y | FP-GCM21B-0_2-e0_2_0_7-MFG |  | 1.451 | charger cell on Bottom; UP1 exposed-pad vias under the grounded USB-C shell
C_UV_BYPASS | \PQCLWCZB | SUPERVISOR | Power_tree_design | Bottom | 25.9806 | 45.6 | 180.0 | Bottom | 45.3983 | 41.6423 | 0.0 |  | FP-GRM155-0_05-IPC_C |  | 0.552 | supervisor (Bottom) beside the converter
C_VBAT | \DLLJRIAK | MCU | MCU_sheet | Top | 59.2 | 43.0 | 0.0 | Top | 48.28 | 39.0 | 0.0 |  | FP-GRM155-0_05-IPC_C |  | 0.254 | STM32 block: B local layout incl. ADC/VCAP/bypass, rigid translation
C_VBUS | \IBSDRNQP | USB_IN | Power_tree_design | Top | 18.7 | 40.6 | 0.0 | Top | 18.7 | 36.6 | 0.0 |  | *MURATA_GRM155C71C105KE11D_0 |  | 0.6 | USB-C + protection: rigid, left edge
C_VDDUSB | \CFQZTGVX | MCU | MCU_sheet | Top | 78.7 | 44.1 | 0.0 | Top | 67.78 | 40.1 | 0.0 |  | FP-GRM155-0_05-IPC_C |  | 0.254 | STM32 block: B local layout incl. ADC/VCAP/bypass, rigid translation
C_WIFI_BULK | \MUJTZXJA | WIFI | MCU_sheet | Bottom | 56.5 | 43.3 | 90.0 | Bottom | 45.58 | 39.3 | 90.0 |  | FP-GRM219-0_2-0_1-IPC_A |  | 0.953 | ST67 block: B local layout, rigid translation (antenna edge)
C_WIFI_EN | \PPSJUUVA | WIFI | MCU_sheet | Top | 55.2 | 38.855 | 0.0 | Top | 44.28 | 34.855 | 0.0 |  | FP-GRM155-0_05-IPC_C |  | 0.254 | ST67 block: B local layout, rigid translation (antenna edge)
C_WIFI_VDD33 | \PENDZXJR | WIFI | MCU_sheet | Top | 53.8 | 35.5 | 270.0 | Top | 42.88 | 31.5 | 270.0 |  | FP-GCM21B-0_2-e0_2_0_7-MFG |  | 0.254 | ST67 block: B local layout, rigid translation (antenna edge)
C_WIFI_VDD33_HF | \VMMAYOTC | WIFI | MCU_sheet | Top | 51.775 | 36.0 | 270.0 | Top | 40.855 | 32.0 | 270.0 |  | FP-GRM155-0_05-MFG |  | 0.254 | ST67 block: B local layout, rigid translation (antenna edge)
C_WIFI_VDDIO1 | \IMKSJAJJ | WIFI | MCU_sheet | Top | 41.0 | 35.5 | 90.0 | Top | 30.08 | 31.5 | 90.0 |  | FP-GCM21B-0_2-e0_2_0_7-MFG |  | 0.254 | ST67 block: B local layout, rigid translation (antenna edge)
C_WIFI_VDDIO1_HF | \GADJTTCJ | WIFI | MCU_sheet | Top | 42.885 | 36.0 | 270.0 | Top | 31.965 | 32.0 | 270.0 |  | FP-GRM155-0_05-MFG |  | 0.254 | ST67 block: B local layout, rigid translation (antenna edge)
C_WIFI_VDDIO2 | \CQCYPVDO | WIFI | MCU_sheet | Top | 55.15 | 46.8 | 180.0 | Top | 44.23 | 42.8 | 180.0 |  | FP-GCM21B-0_2-e0_2_0_7-MFG |  | 0.254 | ST67 block: B local layout, rigid translation (antenna edge)
C_WIFI_VDDIO2_HF | \KDNLJRNG | WIFI | MCU_sheet | Top | 54.7 | 48.8 | 180.0 | Top | 43.78 | 44.8 | 180.0 |  | FP-GRM155-0_05-MFG |  | 0.254 | ST67 block: B local layout, rigid translation (antenna edge)
C_WIFI_X32_IN | \HUBJPMZN | WIFI | MCU_sheet | Top | 49.85 | 32.4 | 90.0 | Top | 38.93 | 28.4 | 90.0 |  | FP-GRM155-0_05-IPC_C |  | 0.254 | ST67 block: B local layout, rigid translation (antenna edge)
C_WIFI_X32_OUT | \ETMOXEBV | WIFI | MCU_sheet | Top | 47.35 | 32.4 | 90.0 | Top | 36.43 | 28.4 | 90.0 |  | FP-GRM155-0_05-IPC_C |  | 0.254 | ST67 block: B local layout, rigid translation (antenna edge)
Cdiv | \ETGTIIWG | AFE | Analog_Shared | Top | 18.6 | 30.0 | 0.0 | Bottom | 16.4 | 26.8 | 0.0 | Y | FP-GRM155-0_05-IPC_C |  | 0.552 | reference divider/filter beside U1 VREF-buffer pins (Bottom); R_ref by J_REF
Cdiv_1 | \TXUADNCR | AFE | Analog_Shared | Top | 27.9 | 25.0 | 180.0 | Bottom | 16.1 | 24.8 | 0.0 | Y | FP-GRM155-0_05-IPC_C |  | 0.552 | reference divider/filter beside U1 VREF-buffer pins (Bottom); R_ref by J_REF
Cdiv_10uF | \KISCTGDZ | AFE | Analog_Shared | Top | 30.2 | 24.8 | 180.0 | Bottom | 13.0 | 26.8 | 0.0 | Y | FP-GCM21B-0_2-e0_2_0_7-MFG |  | 1.451 | reference divider/filter beside U1 VREF-buffer pins (Bottom); R_ref by J_REF
Cservo_1 | \UVWABFOM | AFE | AFE_Channel_1 | Top | 16.8 | 25.7 | 180.0 | Bottom | 21.7 | 17.65 | 0.0 | Y | GRM31x |  | 1.0 | op-amp package-aware group on Bottom directly under its channels (servo/post-amp at their pins)
Cservo_2 | \DWQPLJLU | AFE | AFE_Channel_2 | Top | 33.8 | 24.7 | 180.0 | Bottom | 29.0 | 23.15 | 180.0 | Y | GRM31x |  | 1.0 | op-amp package-aware group on Bottom directly under its channels (servo/post-amp at their pins)
Cservo_3 | \TCDKMOJA | AFE | AFE_Channel_3 | Top | 46.2 | 27.3 | 0.0 | Bottom | 43.2 | 17.65 | 0.0 | Y | GRM31x |  | 1.0 | op-amp package-aware group on Bottom directly under its channels (servo/post-amp at their pins)
Cservo_4 | \BSAHUQLV | AFE | AFE_Channel_4 | Top | 55.8 | 23.5 | 180.0 | Bottom | 50.6 | 23.15 | 180.0 | Y | GRM31x |  | 1.0 | op-amp package-aware group on Bottom directly under its channels (servo/post-amp at their pins)
Cservo_5 | \RHWVFLVY | AFE | AFE_Channel_5 | Top | 68.2 | 26.1 | 0.0 | Bottom | 64.8 | 17.65 | 0.0 | Y | GRM31x |  | 1.0 | op-amp package-aware group on Bottom directly under its channels (servo/post-amp at their pins)
D_CC_ESD | \MGTRVJRM | USB_IN | Power_tree_design | Top | 19.8 | 44.9 | 180.0 | Top | 19.8 | 40.9 | 180.0 |  | SOT95P230X100-3N |  | 0.947 | USB-C + protection: rigid, left edge
D_VBUS | \UMZWIQYE | USB_IN | Power_tree_design | Top | 18.5 | 38.4 | 90.0 | Top | 18.5 | 34.4 | 90.0 |  | FP-SOD323-CA-MFG |  | 0.254 | USB-C + protection: rigid, left edge
INA1 | \DSSHWZCG | AFE | AFE_Channel_1 | Top | 20.0 | 18.2 | 0.0 | Top | 18.7 | 18.2 | 0.0 |  | EMG_AD8237_R3_MSOP8 |  | 1.1 | channel input stage: B template translated to the 10.8 mm BK13 pitch (Top, unchanged internally)
INA2 | \WODSVRPQ | AFE | AFE_Channel_2 | Top | 33.0 | 18.2 | 0.0 | Top | 29.5 | 18.2 | 0.0 |  | EMG_AD8237_R3_MSOP8 |  | 1.1 | channel input stage: B template translated to the 10.8 mm BK13 pitch (Top, unchanged internally)
INA3 | \DEHQBDJR | AFE | AFE_Channel_3 | Top | 46.0 | 18.2 | 0.0 | Top | 40.3 | 18.2 | 0.0 |  | EMG_AD8237_R3_MSOP8 |  | 1.1 | channel input stage: B template translated to the 10.8 mm BK13 pitch (Top, unchanged internally)
INA4 | \XTNWSMDW | AFE | AFE_Channel_4 | Top | 59.0 | 18.2 | 0.0 | Top | 51.1 | 18.2 | 0.0 |  | EMG_AD8237_R3_MSOP8 |  | 1.1 | channel input stage: B template translated to the 10.8 mm BK13 pitch (Top, unchanged internally)
INA5 | \WFMTJBTJ | AFE | AFE_Channel_5 | Top | 72.0 | 18.2 | 0.0 | Top | 61.9 | 18.2 | 0.0 |  | EMG_AD8237_R3_MSOP8 |  | 1.1 | channel input stage: B template translated to the 10.8 mm BK13 pitch (Top, unchanged internally)
JP_WIFI_BOOT | \MTPFUPUN | SERVICE | MCU_sheet | Top | 80.4 | 17.4 | 0.0 | Bottom | 31.194 | 39.205 | 0.0 | Y | EMG_SJ_2P_NO | Y | 0.0 | approved service change: flat footprint (Tag-Connect / probe pad / solder jumper), Not Fitted in PROTO_1_REMOTE_NTC
J_FPC1 | \HRDNIWOC | AFE | AFE_Channel_1 | Top | 20.0 | 12.2 | 0.0 | Top | 18.7 | 12.2 | 0.0 |  | HIROSE_BK13C06-10DS/2-0.35V(895) |  | 0.0 | channel input stage: B template translated to the 10.8 mm BK13 pitch (Top, unchanged internally)
J_FPC2 | \VHZAIESE | AFE | AFE_Channel_2 | Top | 33.0 | 12.2 | 0.0 | Top | 29.5 | 12.2 | 0.0 |  | HIROSE_BK13C06-10DS/2-0.35V(895) |  | 0.0 | channel input stage: B template translated to the 10.8 mm BK13 pitch (Top, unchanged internally)
J_FPC3 | \MNABROKH | AFE | AFE_Channel_3 | Top | 46.0 | 12.2 | 0.0 | Top | 40.3 | 12.2 | 0.0 |  | HIROSE_BK13C06-10DS/2-0.35V(895) |  | 0.0 | channel input stage: B template translated to the 10.8 mm BK13 pitch (Top, unchanged internally)
J_FPC4 | \WOQIDMIX | AFE | AFE_Channel_4 | Top | 59.0 | 12.2 | 0.0 | Top | 51.1 | 12.2 | 0.0 |  | HIROSE_BK13C06-10DS/2-0.35V(895) |  | 0.0 | channel input stage: B template translated to the 10.8 mm BK13 pitch (Top, unchanged internally)
J_FPC5 | \VCZZVCHC | AFE | AFE_Channel_5 | Top | 72.0 | 12.2 | 0.0 | Top | 61.9 | 12.2 | 0.0 |  | HIROSE_BK13C06-10DS/2-0.35V(895) |  | 0.0 | channel input stage: B template translated to the 10.8 mm BK13 pitch (Top, unchanged internally)
J_Li-Po | \VQEFQNBX | BATTERY | Power_tree_design | Top | 12.0 | 33.3 | 0.0 | Top | 24.3689 | 35.4544 | 90.0 |  | HDR1X3 |  | 0.0 | battery header + remote-NTC terminals in the service column (Top)
J_REF | \IDYBTGZF | AFE | Analog_Shared | Top | 12.5 | 19.0 | 0.0 | Top | 11.93 | 12.2 | 0.0 |  | HDR1X2 |  | 0.0 | analog shared reference/branch parts in the analog band
J_SWD | \KSTMQYKV | SERVICE | MCU_sheet | Top | 81.0 | 30.2 | 90.0 | Top | 25.4275 | 28.9 | 90.0 |  | EMG_TC2030_NL | Y | 0.0 | approved service change: flat footprint (Tag-Connect / probe pad / solder jumper), Not Fitted in PROTO_1_REMOTE_NTC
J_USB_C | \OOAEFXTY | USB_IN | Power_tree_design | Top | 12.4 | 43.4 | 270.0 | Top | 12.4 | 39.4 | 270.0 |  | GCT_USB4105-GF-A-060 |  | 3.31 | USB-C + protection: rigid, left edge
L1 | \TMEFFVKY | CONVERTER | Power_tree_design | Top | 34.0 | 42.95 | 180.0 | Bottom | 50.8119 | 42.6335 | 0.0 | Y | FP-DFE21CC_EL-MFG |  | 0.801 | TPS631000 cell flipped whole (B hot loop) under the STM32, clear of ST67 vias/crystal/antenna/ADC corner
LED_CHG | \EZYWKPBA | CHARGER | Power_tree_design | Top | 27.5 | 48.4 | 0.0 | Top | 25.4275 | 43.6 | 90.0 |  | LEDC2012X120N |  | 0.9 | charger cell on Bottom; UP1 exposed-pad vias under the grounded USB-C shell
MCU_VCAP | \YNNCTDAI | MCU | MCU_sheet | Top | 73.6 | 29.4 | 90.0 | Top | 62.68 | 25.4 | 90.0 |  | CAPC2012X135N |  | 1.35 | STM32 block: B local layout incl. ADC/VCAP/bypass, rigid translation
PWR_BTN_N | \FPRAKXRU | BUTTON | Power_tree_design | Top | 34.9 | 47.07 | 0.0 | Top | 14.71 | 27.6207 | 0.0 |  | SW_TS-1187A-B-A-B |  | 0.0 | button (Top) below USB-C
Q_SHDN | \UKRIVBCR | PB_CTRL | Power_tree_design | Bottom | 67.41 | 41.95 | 0.0 | Bottom | 56.49 | 37.95 | 0.0 |  | FP-318-08-IPC_B |  | 1.111 | pushbutton controller (Bottom) under the STM32, rigid with it
RDD1 | \DXKLSNMY | AFE | AFE_Channel_1 | Top | 25.8 | 16.8 | 0.0 | Top | 24.5 | 16.8 | 0.0 |  | RES_ERA2ARB103X |  | 0.0 | channel input stage: B template translated to the 10.8 mm BK13 pitch (Top, unchanged internally)
RDD10 | \EHJREJHQ | AFE | AFE_Channel_4 | Top | 64.8 | 16.8 | 0.0 | Top | 56.9 | 16.8 | 0.0 |  | RES_ERA2ARB103X |  | 0.0 | channel input stage: B template translated to the 10.8 mm BK13 pitch (Top, unchanged internally)
RDD11 | \PLJRMBKM | AFE | AFE_Channel_4 | Top | 64.8 | 15.0 | 0.0 | Top | 56.9 | 15.0 | 0.0 |  | FP-AC0402-MFG |  | 0.254 | channel input stage: B template translated to the 10.8 mm BK13 pitch (Top, unchanged internally)
RDD12 | \CQWOMJFQ | AFE | AFE_Channel_4 | Top | 64.8 | 18.6 | 0.0 | Top | 56.9 | 18.6 | 0.0 |  | RES_ERA2ARB103X |  | 0.0 | channel input stage: B template translated to the 10.8 mm BK13 pitch (Top, unchanged internally)
RDD13 | \PXMMUANO | AFE | AFE_Channel_5 | Top | 77.4 | 16.8 | 0.0 | Top | 67.3 | 16.8 | 0.0 |  | RES_ERA2ARB103X |  | 0.0 | channel input stage: B template translated to the 10.8 mm BK13 pitch (Top, unchanged internally)
RDD14 | \FDBDAWRR | AFE | AFE_Channel_5 | Top | 77.4 | 15.0 | 0.0 | Top | 67.3 | 15.0 | 0.0 |  | FP-AC0402-MFG |  | 0.254 | channel input stage: B template translated to the 10.8 mm BK13 pitch (Top, unchanged internally)
RDD15 | \STOXUDFL | AFE | AFE_Channel_5 | Top | 77.4 | 18.6 | 0.0 | Top | 67.3 | 18.6 | 0.0 |  | RES_ERA2ARB103X |  | 0.0 | channel input stage: B template translated to the 10.8 mm BK13 pitch (Top, unchanged internally)
RDD2 | \HMVRSXGQ | AFE | AFE_Channel_1 | Top | 25.8 | 15.0 | 0.0 | Top | 24.5 | 15.0 | 0.0 |  | FP-AC0402-MFG |  | 0.254 | channel input stage: B template translated to the 10.8 mm BK13 pitch (Top, unchanged internally)
RDD3 | \MJVHHMBB | AFE | AFE_Channel_1 | Top | 25.8 | 18.6 | 0.0 | Top | 24.5 | 18.6 | 0.0 |  | RES_ERA2ARB103X |  | 0.0 | channel input stage: B template translated to the 10.8 mm BK13 pitch (Top, unchanged internally)
RDD4 | \IIVQUIPI | AFE | AFE_Channel_2 | Top | 38.8 | 16.8 | 0.0 | Top | 35.3 | 16.8 | 0.0 |  | RES_ERA2ARB103X |  | 0.0 | channel input stage: B template translated to the 10.8 mm BK13 pitch (Top, unchanged internally)
RDD5 | \WQFXLLGW | AFE | AFE_Channel_2 | Top | 38.8 | 15.0 | 0.0 | Top | 35.3 | 15.0 | 0.0 |  | FP-AC0402-MFG |  | 0.254 | channel input stage: B template translated to the 10.8 mm BK13 pitch (Top, unchanged internally)
RDD6 | \LLIMCPGT | AFE | AFE_Channel_2 | Top | 38.8 | 18.6 | 0.0 | Top | 35.3 | 18.6 | 0.0 |  | RES_ERA2ARB103X |  | 0.0 | channel input stage: B template translated to the 10.8 mm BK13 pitch (Top, unchanged internally)
RDD7 | \TDEFUSFF | AFE | AFE_Channel_3 | Top | 51.8 | 16.8 | 0.0 | Top | 46.1 | 16.8 | 0.0 |  | RES_ERA2ARB103X |  | 0.0 | channel input stage: B template translated to the 10.8 mm BK13 pitch (Top, unchanged internally)
RDD8 | \SWXJGUAX | AFE | AFE_Channel_3 | Top | 51.8 | 15.0 | 0.0 | Top | 46.1 | 15.0 | 0.0 |  | FP-AC0402-MFG |  | 0.254 | channel input stage: B template translated to the 10.8 mm BK13 pitch (Top, unchanged internally)
RDD9 | \WRVCRTAX | AFE | AFE_Channel_3 | Top | 51.8 | 18.6 | 0.0 | Top | 46.1 | 18.6 | 0.0 |  | RES_ERA2ARB103X |  | 0.0 | channel input stage: B template translated to the 10.8 mm BK13 pitch (Top, unchanged internally)
RGN_1 | \GHXDVMLT | AFE | AFE_Channel_1 | Top | 16.9 | 29.9 | 0.0 | Bottom | 21.9 | 21.95 | 270.0 | Y | FP-RT0402-MFG |  | 0.351 | op-amp package-aware group on Bottom directly under its channels (servo/post-amp at their pins)
RGN_2 | \AAUNNEUQ | AFE | AFE_Channel_2 | Top | 33.9 | 28.9 | 0.0 | Bottom | 28.8 | 18.85 | 270.0 | Y | FP-RT0402-MFG |  | 0.351 | op-amp package-aware group on Bottom directly under its channels (servo/post-amp at their pins)
RGN_3 | \HVJKHQAD | AFE | AFE_Channel_3 | Top | 46.9 | 23.7 | 180.0 | Bottom | 43.4 | 21.95 | 270.0 | Y | FP-RT0402-MFG |  | 0.351 | op-amp package-aware group on Bottom directly under its channels (servo/post-amp at their pins)
RGN_4 | \AMATVKYL | AFE | AFE_Channel_4 | Top | 55.9 | 27.7 | 0.0 | Bottom | 50.4 | 18.85 | 270.0 | Y | FP-RT0402-MFG |  | 0.351 | op-amp package-aware group on Bottom directly under its channels (servo/post-amp at their pins)
RGN_5 | \VMZMEQFA | AFE | AFE_Channel_5 | Top | 68.1 | 21.9 | 180.0 | Bottom | 65.0 | 21.95 | 270.0 | Y | FP-RT0402-MFG |  | 0.351 | op-amp package-aware group on Bottom directly under its channels (servo/post-amp at their pins)
RG_1 | \UTRITBAK | AFE | AFE_Channel_1 | Top | 18.5 | 28.625 | 90.0 | Bottom | 18.9 | 21.95 | 270.0 | Y | FP-RT0402-MFG |  | 0.351 | op-amp package-aware group on Bottom directly under its channels (servo/post-amp at their pins)
RG_2 | \SMJLTCCR | AFE | AFE_Channel_2 | Top | 35.5 | 27.625 | 90.0 | Bottom | 31.8 | 18.85 | 270.0 | Y | FP-RT0402-MFG |  | 0.351 | op-amp package-aware group on Bottom directly under its channels (servo/post-amp at their pins)
RG_3 | \IWTKXABD | AFE | AFE_Channel_3 | Top | 44.5 | 24.375 | 270.0 | Bottom | 40.4 | 21.95 | 270.0 | Y | FP-RT0402-MFG |  | 0.351 | op-amp package-aware group on Bottom directly under its channels (servo/post-amp at their pins)
RG_4 | \LGIUMXWW | AFE | AFE_Channel_4 | Top | 57.5 | 26.425 | 90.0 | Bottom | 53.4 | 18.85 | 270.0 | Y | FP-RT0402-MFG |  | 0.351 | op-amp package-aware group on Bottom directly under its channels (servo/post-amp at their pins)
RG_5 | \LNKDIMXT | AFE | AFE_Channel_5 | Top | 66.5 | 23.175 | 270.0 | Bottom | 62.0 | 21.95 | 270.0 | Y | FP-RT0402-MFG |  | 0.351 | op-amp package-aware group on Bottom directly under its channels (servo/post-amp at their pins)
RH_1 | \GTEBNYHJ | AFE | AFE_Channel_1 | Top | 19.4 | 21.75 | 0.0 | Top | 18.1 | 21.75 | 0.0 |  | FP-AC0402-IPC_A |  | 0.254 | channel input stage: B template translated to the 10.8 mm BK13 pitch (Top, unchanged internally)
RH_2 | \TENFJOUW | AFE | AFE_Channel_2 | Top | 32.4 | 21.75 | 0.0 | Top | 28.9 | 21.75 | 0.0 |  | FP-AC0402-IPC_A |  | 0.254 | channel input stage: B template translated to the 10.8 mm BK13 pitch (Top, unchanged internally)
RH_3 | \XMOCRDMS | AFE | AFE_Channel_3 | Top | 45.4 | 21.75 | 0.0 | Top | 39.7 | 21.75 | 0.0 |  | FP-AC0402-IPC_A |  | 0.254 | channel input stage: B template translated to the 10.8 mm BK13 pitch (Top, unchanged internally)
RH_4 | \AABTCOUS | AFE | AFE_Channel_4 | Top | 57.2 | 21.75 | 0.0 | Top | 49.3 | 21.75 | 0.0 |  | FP-AC0402-IPC_A |  | 0.254 | channel input stage: B template translated to the 10.8 mm BK13 pitch (Top, unchanged internally)
RH_5 | \BRQYYKEO | AFE | AFE_Channel_5 | Top | 71.4 | 21.75 | 0.0 | Top | 61.3 | 21.75 | 0.0 |  | FP-AC0402-IPC_A |  | 0.254 | channel input stage: B template translated to the 10.8 mm BK13 pitch (Top, unchanged internally)
RISET | \SSYPHZYI | CHARGER | Power_tree_design | Top | 21.0 | 47.4 | 270.0 | Bottom | 12.5036 | 36.6 | 0.0 | Y | RESC1005X40X25ML05T10 |  | 0.4 | charger cell on Bottom; UP1 exposed-pad vias under the grounded USB-C shell
RJ1 | \ZKMVMVBH | USB_IN | Power_tree_design | Top | 18.9 | 47.1 | 0.0 | Top | 18.9 | 43.1 | 0.0 |  | RESC1005X40X25NL05T10 |  | 0.4 | USB-C + protection: rigid, left edge
RJ2 | \UZEVJROT | USB_IN | Power_tree_design | Top | 18.9 | 48.1 | 0.0 | Top | 18.9 | 44.1 | 0.0 |  | RESC1005X40X25NL05T10 |  | 0.4 | USB-C + protection: rigid, left edge
RL_1 | \HHHGPCFY | AFE | AFE_Channel_1 | Top | 21.4 | 22.3 | 0.0 | Top | 20.1 | 22.3 | 0.0 |  | FP-RT0402-MFG |  | 0.254 | channel input stage: B template translated to the 10.8 mm BK13 pitch (Top, unchanged internally)
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

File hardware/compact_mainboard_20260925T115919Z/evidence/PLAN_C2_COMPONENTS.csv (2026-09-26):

designator | src_uid | group | b_side | b_x | b_y | b_rot | c2_side | c2_x | c2_y | c2_rot | new_footprint
C1_EN1 | \KWJFQQPD | PB_CTRL | Bottom | 75.6099 | 43.35 | 180.0 | Bottom | 64.6899 | 39.35 | 180.0
C1_MCU | \KNSGXSGY | MCU | Top | 59.5 | 37.1 | 180.0 | Top | 48.58 | 33.1 | 180.0
C2_EN1 | \AUBOOCXZ | PB_CTRL | Bottom | 75.51 | 39.95 | 0.0 | Bottom | 64.59 | 35.95 | 0.0
C2_MCU | \TSGCAGJY | MCU | Top | 57.5 | 37.1 | 0.0 | Top | 46.58 | 33.1 | 0.0
C3_EN1 | \BRZQATAL | PB_CTRL | Bottom | 70.31 | 41.95 | 0.0 | Bottom | 59.39 | 37.95 | 0.0
C3_MCU | \TDOPZFWR | MCU | Top | 59.5 | 35.8 | 180.0 | Top | 48.58 | 31.8 | 180.0
C4_MCU | \WPXKGRZF | MCU | Top | 57.5 | 35.8 | 0.0 | Top | 46.58 | 31.8 | 0.0
CCU1 | \DPDOLLAJ | AFE | Top | 22.55 | 20.55 | 0.0 | Top | 21.25 | 20.55 | 0.0
CCU10 | \PGDJRIFP | AFE | Top | 74.55 | 20.55 | 0.0 | Top | 64.45 | 20.55 | 0.0
CCU2 | \MFMCRQQU | AFE | Top | 22.55 | 19.55 | 180.0 | Top | 21.25 | 19.55 | 180.0
CCU3 | \CIMHMRWX | AFE | Top | 35.55 | 19.55 | 180.0 | Top | 32.05 | 19.55 | 180.0
CCU4 | \PJWUZVFE | AFE | Top | 35.55 | 20.55 | 0.0 | Top | 32.05 | 20.55 | 0.0
CCU5 | \PYTUSSRE | AFE | Top | 48.55 | 19.55 | 180.0 | Top | 42.85 | 19.55 | 180.0
CCU6 | \EIDXTRHR | AFE | Top | 48.55 | 20.55 | 0.0 | Top | 42.85 | 20.55 | 0.0
CCU7 | \KKLEFVPX | AFE | Top | 61.55 | 19.55 | 180.0 | Top | 53.65 | 19.55 | 180.0
CCU8 | \XTYCAQJK | AFE | Top | 61.55 | 20.55 | 0.0 | Top | 53.65 | 20.55 | 0.0
CCU9 | \MBHOTVHO | AFE | Top | 74.55 | 19.55 | 180.0 | Top | 64.45 | 19.55 | 180.0
CH_1 | \MIJCOZNW | AFE | Top | 17.5 | 28.625 | 270.0 | Bottom | 20.1 | 21.95 | 270
CH_2 | \VTQJFIQM | AFE | Top | 34.5 | 27.625 | 270.0 | Bottom | 30.6 | 18.85 | 270
CH_3 | \BHEIABIF | AFE | Top | 45.5 | 24.375 | 90.0 | Bottom | 41.6 | 21.95 | 270
CH_4 | \VBHITULI | AFE | Top | 56.5 | 26.425 | 270.0 | Bottom | 52.2 | 18.85 | 270
CH_5 | \SDBPLGOM | AFE | Top | 67.5 | 23.175 | 90.0 | Bottom | 63.2 | 21.95 | 270
CL_1 | \GNLAPLDE | AFE | Top | 14.1 | 30.5 | 0.0 | Bottom | 21.0 | 24.75 | 0
CL_2 | \WSSOZXTJ | AFE | Top | 31.1 | 29.5 | 0.0 | Bottom | 29.7 | 16.05 | 180
CL_3 | \TMGHLPAL | AFE | Top | 49.7 | 23.7 | 180.0 | Bottom | 42.5 | 24.75 | 0
CL_4 | \KJVBWSRF | AFE | Top | 53.1 | 28.3 | 0.0 | Bottom | 51.3 | 16.05 | 180
CL_5 | \YBRHADYL | AFE | Top | 68.5 | 20.5 | 180.0 | Bottom | 64.1 | 24.75 | 0
CU6_1 | \UFCUTPNQ | GAUGE | Bottom | 24.66 | 35.975 | 180.0 | Bottom | 22.16 | 31.975 | 180.0
CUP4 | \TDBSYUJF | CONVERTER | Top | 36.6 | 40.75 | 270.0 | Bottom | 48.2119 | 40.4335 | 270.0
CUP4_1 | \OCTWYPFX | CONVERTER | Top | 31.4 | 40.75 | 270.0 | Bottom | 53.4119 | 40.4335 | 270.0
CUP4_FB | \XDRNRJCW | CONVERTER | Top | 35.3 | 37.45 | 0.0 | Bottom | 49.5119 | 37.1335 | 180.0
CUP5_1 | \KRWEPBDB | LDO | Top | 33.9 | 34.6 | 180.0 | Bottom | 37.85 | 29.3375 | 0.0
CUP5_2 | \ALYAKZJE | LDO | Top | 39.2 | 34.6 | 180.0 | Bottom | 32.55 | 29.3375 | 0.0
CUP5_3 | \GUCDCQUU | LDO | Top | 40.0 | 33.0 | 180.0 | Bottom | 31.75 | 27.7375 | 0.0
CUP5_5 | \ZEQWUVAB | LDO | Top | 33.5 | 36.2 | 180.0 | Bottom | 38.25 | 30.9375 | 0.0
CU_11 | \QTDZGZYC | AFE | Top | 18.3 | 27.0 | 0.0 | Bottom | 19.3 | 19.85 | 0
CU_12 | \KZHXEMRX | AFE | Top | 35.3 | 26.0 | 0.0 | Bottom | 31.4 | 20.95 | 180
CU_14 | \HFAFTJTT | AFE | Top | 57.3 | 24.8 | 0.0 | Bottom | 53.0 | 20.95 | 180
CU_21 | \HBLBLIXO | AFE | Top | 16.7 | 27.0 | 180.0 | Bottom | 21.05 | 19.85 | 0
CU_22 | \QFBGIYQT | AFE | Top | 33.7 | 26.0 | 180.0 | Bottom | 29.65 | 20.95 | 180
CU_24 | \PSMZMIOA | AFE | Top | 55.7 | 24.8 | 180.0 | Bottom | 51.25 | 20.95 | 180
C_ADC1 | \CWYZJILP | ADC_RC | Top | 58.3 | 34.1 | 180.0 | Top | 47.38 | 30.1 | 180.0
C_ADC2 | \ECVYCTDZ | ADC_RC | Top | 58.3 | 32.45 | 180.0 | Top | 47.38 | 28.45 | 180.0
C_ADC3 | \CNHMIMHQ | ADC_RC | Top | 58.3 | 30.8 | 180.0 | Top | 47.38 | 26.8 | 180.0
C_ADC4 | \IWHUAAYK | ADC_RC | Top | 62.6 | 29.4 | 270.0 | Top | 51.68 | 25.4 | 270.0
C_ADC5 | \BBGOTLNQ | ADC_RC | Top | 65.5 | 29.4 | 90.0 | Top | 54.58 | 25.4 | 90.0
C_BAT | \IENRODLZ | CHARGER | Top | 19.5 | 42.0 | 180.0 | Bottom | 13.8832 | 42.0793 | 0
C_DRL_DEC | \EDUIKKDR | AFE | Bottom | 17.0 | 30.2 | 90.0 | Bottom | 13.5058 | 14.528 | 0
C_DRL_FB | \XCYGPLDA | AFE | Bottom | 23.45 | 33.05 | 90.0 | Bottom | 13.5423 | 13.6759 | 0
C_IN_ | \ZMESUDIN | CHARGER | Top | 23.75 | 43.75 | 180.0 | Bottom | 14.35 | 36.4 | 0
C_MCU_BULK | \XNGEFMHP | MCU | Top | 78.75 | 47.9 | 90.0 | Top | 67.83 | 43.9 | 90.0
C_MCU_VDD1 | \QBPNORLY | MCU | Top | 59.2 | 40.5 | 0.0 | Top | 48.28 | 36.5 | 0.0
C_MCU_VDD2 | \BIEOJUNV | MCU | Top | 64.0 | 29.7 | 90.0 | Top | 53.08 | 25.7 | 90.0
C_MCU_VDD3 | \AUVFQSTI | MCU | Top | 76.0 | 29.9 | 90.0 | Top | 65.08 | 25.9 | 90.0
C_MCU_VDD4 | \ABSRTBCD | MCU | Top | 78.7 | 45.5 | 0.0 | Top | 67.78 | 41.5 | 0.0
C_MCU_VDD5 | \OOSRRHMX | MCU | Top | 63.0 | 49.03 | 0.0 | Top | 52.08 | 45.03 | 0.0
C_NRST | \UTOMCBIX | MCU | Top | 57.1 | 39.0 | 180.0 | Top | 46.18 | 35.0 | 180.0
C_OUT_ | \PIABGTTK | CHARGER | Top | 26.4 | 41.4 | 0.0 | Bottom | 16.6 | 39.65 | 90
C_UV_BYPASS | \PQCLWCZB | SUPERVISOR | Bottom | 25.9806 | 45.6 | 180.0 | Bottom | 45.3983 | 41.6423 | 0.0
C_VBAT | \DLLJRIAK | MCU | Top | 59.2 | 43.0 | 0.0 | Top | 48.28 | 39.0 | 0.0
C_VBUS | \IBSDRNQP | USB_IN | Top | 18.7 | 40.6 | 0.0 | Top | 18.7 | 36.6 | 0.0
C_VDDUSB | \CFQZTGVX | MCU | Top | 78.7 | 44.1 | 0.0 | Top | 67.78 | 40.1 | 0.0
C_WIFI_BULK | \MUJTZXJA | WIFI | Bottom | 56.5 | 43.3 | 90.0 | Bottom | 45.58 | 39.3 | 90.0
C_WIFI_EN | \PPSJUUVA | WIFI | Top | 55.2 | 38.855 | 0.0 | Top | 44.28 | 34.855 | 0.0
C_WIFI_VDD33 | \PENDZXJR | WIFI | Top | 53.8 | 35.5 | 270.0 | Top | 42.88 | 31.5 | 270.0
C_WIFI_VDD33_HF | \VMMAYOTC | WIFI | Top | 51.775 | 36.0 | 270.0 | Top | 40.855 | 32.0 | 270.0
C_WIFI_VDDIO1 | \IMKSJAJJ | WIFI | Top | 41.0 | 35.5 | 90.0 | Top | 30.08 | 31.5 | 90.0
C_WIFI_VDDIO1_HF | \GADJTTCJ | WIFI | Top | 42.885 | 36.0 | 270.0 | Top | 31.965 | 32.0 | 270.0
C_WIFI_VDDIO2 | \CQCYPVDO | WIFI | Top | 55.15 | 46.8 | 180.0 | Top | 44.23 | 42.8 | 180.0
C_WIFI_VDDIO2_HF | \KDNLJRNG | WIFI | Top | 54.7 | 48.8 | 180.0 | Top | 43.78 | 44.8 | 180.0
C_WIFI_X32_IN | \HUBJPMZN | WIFI | Top | 49.85 | 32.4 | 90.0 | Top | 38.93 | 28.4 | 90.0
C_WIFI_X32_OUT | \ETMOXEBV | WIFI | Top | 47.35 | 32.4 | 90.0 | Top | 36.43 | 28.4 | 90.0
Cdiv | \ETGTIIWG | AFE | Top | 18.6 | 30.0 | 0.0 | Bottom | 16.4 | 26.8 | 0
Cdiv_1 | \TXUADNCR | AFE | Top | 27.9 | 25.0 | 180.0 | Bottom | 16.1 | 24.8 | 0
Cdiv_10uF | \KISCTGDZ | AFE | Top | 30.2 | 24.8 | 180.0 | Bottom | 13.0 | 26.8 | 0
Cservo_1 | \UVWABFOM | AFE | Top | 16.8 | 25.7 | 180.0 | Bottom | 21.7 | 17.65 | 0
Cservo_2 | \DWQPLJLU | AFE | Top | 33.8 | 24.7 | 180.0 | Bottom | 29.0 | 23.15 | 180
Cservo_3 | \TCDKMOJA | AFE | Top | 46.2 | 27.3 | 0.0 | Bottom | 43.2 | 17.65 | 0
Cservo_4 | \BSAHUQLV | AFE | Top | 55.8 | 23.5 | 180.0 | Bottom | 50.6 | 23.15 | 180
Cservo_5 | \RHWVFLVY | AFE | Top | 68.2 | 26.1 | 0.0 | Bottom | 64.8 | 17.65 | 0
D_CC_ESD | \MGTRVJRM | USB_IN | Top | 19.8 | 44.9 | 180.0 | Top | 19.8 | 40.9 | 180.0
D_VBUS | \UMZWIQYE | USB_IN | Top | 18.5 | 38.4 | 90.0 | Top | 18.5 | 34.4 | 90.0
FP:TP_3V0_ANA |  | FREEPAD_LDO | Top | 38.75 | 35.7 | 0.0 | Top | 34.1995 | 29.2875 | 0
FP:TP_3V3_DIG |  | FREEPAD_CONVERTER | Top | 36.5 | 43.25 | 0.0 | Top | 48.6951 | 41.7863 | 0
FP:TP_GND_ANA |  | FREEPAD_AFE | Top | 16.25 | 28.0 | 0.0 | Top | 12.5 | 16.2 | 0
FP:TP_GND_DIG |  | FREEPAD_MCU | Top | 82.5 | 43.0 | 0.0 | Top | 56.671 | 44.829 | 0
FP:TP_GND_PWR |  | FREEPAD_BATTERY | Top | 19.3 | 32.35 | 0.0 | Top | 22.3847 | 35.7051 | 0
FP:TP_VBAT_CELL |  | FREEPAD_BATTERY | Top | 17.0 | 31.25 | 0.0 | Top | 26.3532 | 40.7851 | 0
FP:TP_VBUS |  | FREEPAD_CHARGER | Top | 26.25 | 43.9 | 0.0 | Top | 14.2247 | 34.2521 | 0
FP:TP_VOUT_1 |  | FREEPAD_ADC_RC | Top | 56.25 | 33.75 | 0.0 | Top | 45.33 | 29.75 | 0.0
FP:TP_VOUT_2 |  | FREEPAD_ADC_RC | Top | 59.25 | 29.25 | 0.0 | Top | 48.33 | 25.25 | 0.0
FP:TP_VOUT_3 |  | FREEPAD_ADC_RC | Top | 56.75 | 29.25 | 0.0 | Top | 45.83 | 25.25 | 0.0
FP:TP_VOUT_4 |  | FREEPAD_ADC_RC | Top | 55.25 | 31.25 | 0.0 | Top | 44.33 | 27.25 | 0.0
FP:TP_VOUT_5 |  | FREEPAD_ADC_RC | Top | 68.5 | 28.5 | 0.0 | Top | 57.58 | 24.5 | 0.0
FP:TP_VREF_A |  | FREEPAD_AFE | Top | 25.75 | 23.75 | 0.0 | Top | 12.5 | 18.2 | 0
FP:TP_VREF_B_SRC |  | FREEPAD_AFE | Top | 25.75 | 30.25 | 0.0 | Top | 12.5 | 20.2 | 0
FP:TP_VSYS |  | FREEPAD_CHARGER | Top | 25.5 | 39.9 | 0.0 | Top | 18.6168 | 38.6593 | 0
INA1 | \DSSHWZCG | AFE | Top | 20.0 | 18.2 | 0.0 | Top | 18.7 | 18.2 | 0.0
INA2 | \WODSVRPQ | AFE | Top | 33.0 | 18.2 | 0.0 | Top | 29.5 | 18.2 | 0.0
INA3 | \DEHQBDJR | AFE | Top | 46.0 | 18.2 | 0.0 | Top | 40.3 | 18.2 | 0.0
INA4 | \XTNWSMDW | AFE | Top | 59.0 | 18.2 | 0.0 | Top | 51.1 | 18.2 | 0.0
INA5 | \WFMTJBTJ | AFE | Top | 72.0 | 18.2 | 0.0 | Top | 61.9 | 18.2 | 0.0
JP_WIFI_BOOT | \MTPFUPUN | SERVICE | Top | 80.4 | 17.4 | 0.0 | Bottom | 31.194 | 39.205 | 0 | Y
J_FPC1 | \HRDNIWOC | AFE | Top | 20.0 | 12.2 | 0.0 | Top | 18.7 | 12.2 | 0.0
J_FPC2 | \VHZAIESE | AFE | Top | 33.0 | 12.2 | 0.0 | Top | 29.5 | 12.2 | 0.0
J_FPC3 | \MNABROKH | AFE | Top | 46.0 | 12.2 | 0.0 | Top | 40.3 | 12.2 | 0.0
J_FPC4 | \WOQIDMIX | AFE | Top | 59.0 | 12.2 | 0.0 | Top | 51.1 | 12.2 | 0.0
J_FPC5 | \VCZZVCHC | AFE | Top | 72.0 | 12.2 | 0.0 | Top | 61.9 | 12.2 | 0.0
J_Li-Po | \VQEFQNBX | BATTERY | Top | 12.0 | 33.3 | 0.0 | Top | 24.3689 | 35.4544 | 90
J_REF | \IDYBTGZF | AFE | Top | 12.5 | 19.0 | 0.0 | Top | 11.93 | 12.2 | 0
J_SWD | \KSTMQYKV | SERVICE | Top | 81.0 | 30.2 | 90.0 | Top | 25.4275 | 28.9 | 90 | Y
J_USB_C | \OOAEFXTY | USB_IN | Top | 12.4 | 43.4 | 270.0 | Top | 12.4 | 39.4 | 270.0
L1 | \TMEFFVKY | CONVERTER | Top | 34.0 | 42.95 | 180.0 | Bottom | 50.8119 | 42.6335 | 0.0
LED_CHG | \EZYWKPBA | CHARGER | Top | 27.5 | 48.4 | 0.0 | Top | 25.4275 | 43.6 | 90
MCU_VCAP | \YNNCTDAI | MCU | Top | 73.6 | 29.4 | 90.0 | Top | 62.68 | 25.4 | 90.0
PWR_BTN_N | \FPRAKXRU | BUTTON | Top | 34.9 | 47.07 | 0.0 | Top | 14.71 | 27.6207 | 0
Q_SHDN | \UKRIVBCR | PB_CTRL | Bottom | 67.41 | 41.95 | 0.0 | Bottom | 56.49 | 37.95 | 0.0
RDD1 | \DXKLSNMY | AFE | Top | 25.8 | 16.8 | 0.0 | Top | 24.5 | 16.8 | 0.0
RDD10 | \EHJREJHQ | AFE | Top | 64.8 | 16.8 | 0.0 | Top | 56.9 | 16.8 | 0.0
RDD11 | \PLJRMBKM | AFE | Top | 64.8 | 15.0 | 0.0 | Top | 56.9 | 15.0 | 0.0
RDD12 | \CQWOMJFQ | AFE | Top | 64.8 | 18.6 | 0.0 | Top | 56.9 | 18.6 | 0.0
RDD13 | \PXMMUANO | AFE | Top | 77.4 | 16.8 | 0.0 | Top | 67.3 | 16.8 | 0.0
RDD14 | \FDBDAWRR | AFE | Top | 77.4 | 15.0 | 0.0 | Top | 67.3 | 15.0 | 0.0
RDD15 | \STOXUDFL | AFE | Top | 77.4 | 18.6 | 0.0 | Top | 67.3 | 18.6 | 0.0
RDD2 | \HMVRSXGQ | AFE | Top | 25.8 | 15.0 | 0.0 | Top | 24.5 | 15.0 | 0.0
RDD3 | \MJVHHMBB | AFE | Top | 25.8 | 18.6 | 0.0 | Top | 24.5 | 18.6 | 0.0
RDD4 | \IIVQUIPI | AFE | Top | 38.8 | 16.8 | 0.0 | Top | 35.3 | 16.8 | 0.0
RDD5 | \WQFXLLGW | AFE | Top | 38.8 | 15.0 | 0.0 | Top | 35.3 | 15.0 | 0.0
RDD6 | \LLIMCPGT | AFE | Top | 38.8 | 18.6 | 0.0 | Top | 35.3 | 18.6 | 0.0
RDD7 | \TDEFUSFF | AFE | Top | 51.8 | 16.8 | 0.0 | Top | 46.1 | 16.8 | 0.0
RDD8 | \SWXJGUAX | AFE | Top | 51.8 | 15.0 | 0.0 | Top | 46.1 | 15.0 | 0.0
RDD9 | \WRVCRTAX | AFE | Top | 51.8 | 18.6 | 0.0 | Top | 46.1 | 18.6 | 0.0
RGN_1 | \GHXDVMLT | AFE | Top | 16.9 | 29.9 | 0.0 | Bottom | 21.9 | 21.95 | 270
RGN_2 | \AAUNNEUQ | AFE | Top | 33.9 | 28.9 | 0.0 | Bottom | 28.8 | 18.85 | 270
RGN_3 | \HVJKHQAD | AFE | Top | 46.9 | 23.7 | 180.0 | Bottom | 43.4 | 21.95 | 270
RGN_4 | \AMATVKYL | AFE | Top | 55.9 | 27.7 | 0.0 | Bottom | 50.4 | 18.85 | 270
RGN_5 | \VMZMEQFA | AFE | Top | 68.1 | 21.9 | 180.0 | Bottom | 65.0 | 21.95 | 270
RG_1 | \UTRITBAK | AFE | Top | 18.5 | 28.625 | 90.0 | Bottom | 18.9 | 21.95 | 270
RG_2 | \SMJLTCCR | AFE | Top | 35.5 | 27.625 | 90.0 | Bottom | 31.8 | 18.85 | 270
RG_3 | \IWTKXABD | AFE | Top | 44.5 | 24.375 | 270.0 | Bottom | 40.4 | 21.95 | 270
RG_4 | \LGIUMXWW | AFE | Top | 57.5 | 26.425 | 90.0 | Bottom | 53.4 | 18.85 | 270
RG_5 | \LNKDIMXT | AFE | Top | 66.5 | 23.175 | 270.0 | Bottom | 62.0 | 21.95 | 270
RH_1 | \GTEBNYHJ | AFE | Top | 19.4 | 21.75 | 0.0 | Top | 18.1 | 21.75 | 0.0
RH_2 | \TENFJOUW | AFE | Top | 32.4 | 21.75 | 0.0 | Top | 28.9 | 21.75 | 0.0
RH_3 | \XMOCRDMS | AFE | Top | 45.4 | 21.75 | 0.0 | Top | 39.7 | 21.75 | 0.0
RH_4 | \AABTCOUS | AFE | Top | 57.2 | 21.75 | 0.0 | Top | 49.3 | 21.75 | 0.0
RH_5 | \BRQYYKEO | AFE | Top | 71.4 | 21.75 | 0.0 | Top | 61.3 | 21.75 | 0.0
RISET | \SSYPHZYI | CHARGER | Top | 21.0 | 47.4 | 270.0 | Bottom | 12.5036 | 36.6 | 0
RJ1 | \ZKMVMVBH | USB_IN | Top | 18.9 | 47.1 | 0.0 | Top | 18.9 | 43.1 | 0.0
RJ2 | \UZEVJROT | USB_IN | Top | 18.9 | 48.1 | 0.0 | Top | 18.9 | 44.1 | 0.0
RL_1 | \HHHGPCFY | AFE | Top | 21.4 | 22.3 | 0.0 | Top | 20.1 | 22.3 | 0.0
RL_2 | \TELITLFC | AFE | Top | 34.4 | 22.3 | 0.0 | Top | 30.9 | 22.3 | 0.0
RL_3 | \XBCKMMOI | AFE | Top | 47.4 | 22.3 | 0.0 | Top | 41.7 | 22.3 | 0.0
RL_4 | \BXVEUIPV | AFE | Top | 60.2 | 21.7 | 0.0 | Top | 52.3 | 21.7 | 0.0
RL_5 | \DRPDTLDH | AFE | Top | 73.4 | 22.3 | 0.0 | Top | 63.3 | 22.3 | 0.0
RUP_3 | \FVAOALWX | CONVERTER | Top | 35.3 | 38.45 | 0.0 | Bottom | 49.5119 | 38.1335 | 180.0
RUP_4 | \DIXYKNNS | CONVERTER | Top | 33.4 | 38.45 | 0.0 | Bottom | 51.4119 | 38.1335 | 180.0
RV1 | \FJSJEKUM | AFE | Top | 28.2 | 26.0 | 180.0 | Bottom | 12.0 | 24.8 | 0
RV2 | \ACJROGAV | AFE | Top | 28.2 | 27.0 | 0.0 | Bottom | 14.1 | 24.8 | 0
R_ADC1 | \TKCPYGKF | ADC_RC | Top | 60.0 | 34.1 | 90.0 | Top | 49.08 | 30.1 | 90.0
R_ADC2 | \CFTIPEZE | ADC_RC | Top | 60.0 | 32.45 | 90.0 | Top | 49.08 | 28.45 | 90.0
R_ADC3 | \VPQHMOBO | ADC_RC | Top | 60.0 | 30.8 | 90.0 | Top | 49.08 | 26.8 | 90.0
R_ADC4 | \RNNLSOJY | ADC_RC | Top | 60.8 | 29.4 | 0.0 | Top | 49.88 | 25.4 | 0.0
R_ADC5 | \CWCXIEPU | ADC_RC | Top | 67.0 | 28.5 | 180.0 | Top | 56.08 | 24.5 | 180.0
R_AL | \KHERGLLP | GAUGE | Bottom | 19.66 | 35.475 | 180.0 | Bottom | 17.16 | 31.475 | 180.0
R_CHG_LED | \DPJOEUUL | CHARGER | Top | 28.0 | 46.5 | 0.0 | Bottom | 18.2 | 40.15 | 90
R_DRL_FB | \EIJHLSNJ | AFE | Bottom | 23.45 | 30.2 | 90.0 | Bottom | 12.445 | 16.7928 | 0
R_DRL_OUT1 | \SMIJZRZG | AFE | Bottom | 14.0 | 29.5 | 0.0 | Bottom | 18.1 | 15.2 | 90
R_DRL_OUT2 | \QLOEDQON | AFE | Bottom | 14.0 | 31.3 | 0.0 | Bottom | 19.8963 | 14.9993 | 90
R_DRL_SEL | \DMIZMQOS | AFE | Bottom | 11.9 | 21.7 | 0.0 | Bottom | 22.1418 | 12.8328 | 90
R_DRL_VA1 | \RIFJGQGL | AFE | Bottom | 12.5 | 23.5 | 0.0 | Bottom | 16.95 | 11.7 | 270
R_DRL_VA2 | \MVYFQFIQ | AFE | Bottom | 15.85 | 23.5 | 0.0 | Bottom | 27.75 | 11.7 | 270
R_DRL_VA3 | \UBNLRAIB | AFE | Bottom | 19.2 | 23.5 | 0.0 | Bottom | 38.55 | 11.7 | 270
R_DRL_VA4 | \ADWZPFZU | AFE | Bottom | 22.55 | 23.5 | 0.0 | Bottom | 49.35 | 11.7 | 270
R_DRL_VA5 | \SHYIMMPG | AFE | Bottom | 25.9 | 23.5 | 0.0 | Bottom | 60.15 | 11.7 | 270
R_DRL_VB1 | \LZLPZBNE | AFE | Bottom | 12.5 | 25.3 | 0.0 | Bottom | 18.7 | 11.7 | 270
R_DRL_VB2 | \QVAUFHQD | AFE | Bottom | 15.85 | 25.3 | 0.0 | Bottom | 29.5 | 11.7 | 270
R_DRL_VB3 | \OJYINECL | AFE | Bottom | 19.2 | 25.3 | 0.0 | Bottom | 40.3 | 11.7 | 270
R_DRL_VB4 | \IHMMSDCU | AFE | Bottom | 22.55 | 25.3 | 0.0 | Bottom | 51.1 | 11.7 | 270
R_DRL_VB5 | \GLRUZBWG | AFE | Bottom | 25.9 | 25.3 | 0.0 | Bottom | 61.9 | 11.7 | 270
R_DRL_VC1 | \IHATGGJF | AFE | Bottom | 12.5 | 27.1 | 0.0 | Bottom | 20.45 | 11.7 | 270
R_DRL_VC2 | \EAWUJWHA | AFE | Bottom | 15.85 | 27.1 | 0.0 | Bottom | 31.25 | 11.7 | 270
R_DRL_VC3 | \XXOACUDZ | AFE | Bottom | 19.2 | 27.1 | 0.0 | Bottom | 42.05 | 11.7 | 270
R_DRL_VC4 | \HGWJYRWC | AFE | Bottom | 22.55 | 27.1 | 0.0 | Bottom | 52.85 | 11.7 | 270
R_DRL_VC5 | \AGXVAPNG | AFE | Bottom | 25.9 | 27.1 | 0.0 | Bottom | 63.65 | 11.7 | 270
R_EN | \HYXOCZMX | SUPERVISOR | Bottom | 27.6806 | 48.8 | 180.0 | Bottom | 43.6983 | 38.4423 | 0.0
R_EN1_1 | \TTIIGMKO | PB_CTRL | Bottom | 75.41 | 44.25 | 180.0 | Bottom | 64.49 | 40.25 | 180.0
R_EN1_BIAS | \EAFZMWMK | CHARGER | Top | 22.9 | 38.4 | 90.0 | Bottom | 14.2308 | 44.1956 | 90
R_EN_PD | \LCJTGOVC | PULLS_PWR | Bottom | 34.4 | 31.6 | 180.0 | Bottom | 37.9222 | 26.6685 | 0
R_INT_PULLUP | \KYNUZFOC | PB_CTRL | Bottom | 70.51 | 39.75 | 0.0 | Bottom | 59.59 | 35.75 | 0.0
R_KILL_PU | \SCZGXJMM | PB_CTRL | Bottom | 70.51 | 43.45 | 180.0 | Bottom | 59.59 | 39.45 | 180.0
R_LIM | \XBDBQAEM | CHARGER | Top | 26.0 | 42.7 | 180.0 | Bottom | 17.0474 | 37.5365 | 0
R_MCU_BOOT0_PD | \VDIEWLTB | MCU | Top | 66.0 | 49.06 | 0.0 | Top | 55.08 | 45.06 | 0.0
R_NRST | \QJKCHWBH | MCU | Top | 59.0 | 39.0 | 180.0 | Top | 48.08 | 35.0 | 180.0
R_PGOOD | \EFWQJZYR | PULLS_PWR | Bottom | 27.5 | 38.6 | 90.0 | Bottom | 11.4521 | 42.2995 | 0
R_SCL | \ZJWQWTCI | GAUGE | Bottom | 19.86 | 36.575 | 180.0 | Bottom | 17.36 | 32.575 | 180.0
R_SDA | \VKNWNXOB | GAUGE | Bottom | 19.86 | 37.575 | 180.0 | Bottom | 17.36 | 33.575 | 180.0
R_SHDN_G | \QHLZMLVE | PB_CTRL | Bottom | 64.6099 | 41.25 | 180.0 | Bottom | 53.6899 | 37.25 | 180.0
R_SHDN_PD | \RXBFSGOA | PB_CTRL | Bottom | 64.6099 | 42.45 | 180.0 | Bottom | 53.6899 | 38.45 | 180.0
R_SPI_CS | \SNTSEMSL | MCU | Top | 69.4 | 30.05 | 90.0 | Top | 58.48 | 26.05 | 90.0
R_SPI_MISO | \FDPXAZPM | WIFI | Top | 40.0 | 48.2 | 180.0 | Top | 29.08 | 44.2 | 180.0
R_SPI_MOSI | \SJCHDUPS | MCU | Top | 68.0 | 30.05 | 90.0 | Top | 57.08 | 26.05 | 90.0
R_SPI_SCK | \OHVPHCBD | MCU | Top | 66.6 | 30.05 | 90.0 | Top | 55.68 | 26.05 | 90.0
R_TH_BAT | \ZLRLAHMN | BATTERY | Top | 20.7 | 33.9 | 0.0 | Top | 26.9389 | 37.853 | 90
R_TMR | \QYGIVNSS | CHARGER | Top | 27.4 | 44.0 | 90.0 | Bottom | 14.1498 | 34.8283 | 90
R_TS_BOTTOM | \IGQWSYEF | CHARGER | Top | 22.9 | 45.9 | 90.0 | Bottom | 10.9029 | 36.6731 | 90
R_TS_SER | \NAFFNVVJ | CHARGER | Top | 22.5 | 44.6 | 0.0 | Bottom | 10.8 | 38.65 | 270
R_TS_TOP | \XVULIBXW | CHARGER | Top | 22.0 | 46.0 | 90.0 | Bottom | 11.1945 | 40.349 | 90
R_VREF1 | \QFKDQFCI | AFE | Top | 28.2 | 30.2 | 90.0 | Top | 22.6 | 12.4 | 90
R_VREF2 | \JMOUPRZI | AFE | Top | 30.0 | 31.4 | 90.0 | Top | 33.4 | 12.4 | 90
R_VREF3 | \JVORZKQG | AFE | Top | 31.8 | 31.4 | 90.0 | Top | 44.2 | 12.4 | 90
R_VREF4 | \AUHMVSOL | AFE | Top | 34.1 | 31.0 | 90.0 | Top | 55.0 | 12.4 | 90
R_VREF5 | \BBZTKGIX | AFE | Top | 35.4 | 30.2 | 90.0 | Top | 65.8 | 12.4 | 90
R_WIFI_BOOT_OVR | \JHBKEAOF | SERVICE | Bottom | 81.2 | 13.5 | 180.0 | Bottom | 31.194 | 37.205 | 0
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

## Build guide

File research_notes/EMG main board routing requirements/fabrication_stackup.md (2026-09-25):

# Fabrication & stack-up limits for the 4-layer JLCPCB EMG main board (80 × 45 mm, FR-4, ENIG, through vias)

Scope: JLCPCB 4-layer fabrication/assembly limits, the exact stack-up, 50 Ω geometry, and copper/via current capacity, each compared with the project's exported rules. All web sources were accessed 2026-09-24. JLC capability pages show only "© 2026" and no revision number. Project files were read only: [RULES.txt](file:///C:/Users/PMLS/Desktop/emg-saw/hardware/pcb_layout_2026-09-23_drl/evidence/NATIVE_FINAL_20260924T015854610Z/RULES.txt), [STACK.txt](file:///C:/Users/PMLS/Desktop/emg-saw/hardware/pcb_layout_2026-09-23_drl/evidence/NATIVE_FINAL_20260924T015854610Z/STACK.txt), [layout brief](file:///C:/Users/PMLS/Desktop/emg-saw/hardware/pcb_layout_2026-09-16/Documentation/EMG_Main_PCB_Layout_Master_Prompt_2026-09-16.md). The impedance and current numbers in the "Inferences" sections are my own calculations. Their methods and assumptions are stated there, and they are not JLC calculator output.

## Q1 — JLCPCB published 4-layer capabilities vs the project's rules

### Takeaway
Every routing dimension the project uses is within JLC's published 4-layer capability, most with large margin: 0.15 mm tracks vs a 0.09 mm minimum, 0.20 mm clearance vs 0.09 mm, and 0.6/0.3 vias with a 0.15 mm ring and no surcharge. Five exported rule values need attention:
- The edge rule is 0.254 mm, not the intended 0.50 mm. That passes a routed edge but fails a V-cut edge (0.4 mm).
- The solder-mask sliver rule (0.10 mm) is exactly at JLC's limit for green mask and fails for black/white.
- The in-footprint 0.10–0.125 mm pad-to-pad exceptions are below JLC's stated "SMD pad to pad 0.15 mm". They are still above the 0.09 mm spacing limit.
- The −0.35 mm via-tenting rule described in the brief does not appear in the export.
- The 0.45/0.2 mm via sits exactly on JLC's surcharge threshold.

### Cited Findings
**Tracks/spacing**
- Minimum track/spacing, multilayer, 1 oz: "0.09 / 0.09 mm (3.5 / 3.5 mil). 3 mil is acceptable in BGA fan-outs". For 1–2 layers it is 0.10/0.10 mm. With 2 oz copper it is 0.15/0.15 mm (multilayer) and 0.16/0.16 mm (2-layer). Track width tolerance is ±20%. — [JLCPCB, "PCB Manufacturing & Assembly Capabilities"](https://jlcpcb.com/capabilities/pcb-capabilities)
- The page gives no separate trace/space figure for **inner 0.5 oz** copper in the extracted text; the multilayer 0.09/0.09 mm row is the applicable limit. Finished copper options are outer 1 oz/2 oz and inner 0.5 oz (default)/1 oz/2 oz. — [JLCPCB capabilities](https://jlcpcb.com/capabilities/pcb-capabilities)

**Vias and holes**
- Minimum via: "0.15 mm hole size / 0.25 mm via diameter" (multilayer). Cost rule: "0.15mm hole size with any size via diameter, and 0.2mm or 0.25mm hole size with via diameter less than 0.45mm, will cost more." The page also gives a recommended minimum via hole of 0.2 mm. — [JLCPCB capabilities](https://jlcpcb.com/capabilities/pcb-capabilities)
- Via annular ring: "Via diameter should be 0.1mm (0.15mm preferred) larger than Via hole size", i.e. a ring of 0.05 mm minimum and 0.075 mm preferred. — [JLCPCB capabilities](https://jlcpcb.com/capabilities/pcb-capabilities). This matches the POFV rule "0.05 mm minimum, 0.075 mm preferred" in [JLCPCB news, "Free Via-in-Pad on 6-20 Layer PCBs with POFV" (2022-11-02)](https://jlcpcb.com/news/free-via-in-pad-6-20-layer-pcbs-pofv).
- Via hole-to-hole spacing is 0.2 mm; pad (PTH) hole-to-hole spacing is 0.45 mm. — [JLCPCB capabilities](https://jlcpcb.com/capabilities/pcb-capabilities)
- Via **hole** to track is 0.2 mm. Inner-layer via hole to copper is 0.2 mm. Inner-layer PTH hole to copper is 0.3 mm. PTH to track is 0.28 mm (0.35 mm recommended). NPTH to track is 0.2 mm. — [JLCPCB capabilities](https://jlcpcb.com/capabilities/pcb-capabilities)
- PTH annular ring (1 oz multilayer) is "≧0.20mm" recommended with an absolute minimum of 0.15 mm; 2 oz needs 0.254 mm or more. — [JLCPCB capabilities](https://jlcpcb.com/capabilities/pcb-capabilities)
- Drill: range 0.15–6.3 mm (multilayer); through-hole tolerance +0.13/−0.08 mm; hole position ±0.05 mm; "Average Hole Plating Thickness: 18μm". — [JLCPCB capabilities](https://jlcpcb.com/capabilities/pcb-capabilities)

**Pads**
- Pad-to-track is minimum 0.1 mm ("stay well above if possible"). SMD pad-to-pad (different nets) is 0.15 mm. — [JLCPCB capabilities](https://jlcpcb.com/capabilities/pcb-capabilities)
- BGA: minimum pad 0.2 mm (the extraction says this requires ENIG). BGA pad to trace is ≥0.1 mm (0.09 mm minimum on multilayer). — [JLCPCB capabilities](https://jlcpcb.com/capabilities/pcb-capabilities)

**Solder mask and via covering**
- Solder-mask bridge (dam), 1 oz: minimum 0.10 mm for green/red/yellow/blue/purple and 0.13 mm for black/white; 2 oz needs 0.20 mm. The page lists solder-mask expansion as "1:1" and says to keep "at least 0.09 mm" mask clearance from traces (exact meaning ambiguous in the extraction). — [JLCPCB capabilities](https://jlcpcb.com/capabilities/pcb-capabilities)
- Via covering options on the capabilities page are soldermask-filled (plugged), "Epoxy Filled & Capped" and "Copper paste Filled&Capped". Epoxy/paste filling is "compatible with via diameters from 0.15 to 0.55 mm". Filled vias need "≥ 0.35 mm clearance from other soldermask openings". Epoxy-filled & capped "is the default for 6-layer and above". — [JLCPCB capabilities](https://jlcpcb.com/capabilities/pcb-capabilities)
- Via-covering article (last updated 2026-09-09):
  - Plugged/filled via holes "should not be larger than 0.5 mm".
  - Tented vias should ideally be "0.4 mm or less and no larger than 0.5 mm"; "No complaints are accepted for this problem."
  - "Vias with a distance less than 0.35mm from the pad cannot be plugged with ink. Such vias can be plugged with epoxy or copper"; the same applies to holes in pads.
  - Which vias to plug can be specified by note, image, or "which via diameters should be plugged".
  — [JLCPCB help, "Via Covering: Tented, Untented, Plugged, Epoxy-Filled and Copper-epoxy-filled"](https://jlcpcb.com/help/article/pcb-via-covering)
- POFV is free and default on 6–20 layers; "POFV for 4-layer PCBs still requires charges"; POFV via hole range is 0.2–0.5 mm; POFV vias should be "placed more than 0.45 mm from regular PTHs or NPTHs". — [JLCPCB news (2022-11-02)](https://jlcpcb.com/news/free-via-in-pad-6-20-layer-pcbs-pofv)

**Board edge and outline**
- Copper to routed board edge is "≧0.2 mm"; copper to V-cut edge is "≧0.4 mm". Routed-edge tolerance is ±0.2 mm (regular) or ±0.1 mm (high precision); V-cut tolerance is ±0.4 mm. — [JLCPCB capabilities](https://jlcpcb.com/capabilities/pcb-capabilities)
- Board thickness range is 0.4–4.5 mm (standard values include 1.2 mm). Tolerance is ±10% for boards ≥1.0 mm. The 4-layer maximum size is 663 × 593 mm. — [JLCPCB capabilities](https://jlcpcb.com/capabilities/pcb-capabilities)
- Castellated holes need ≥0.5 mm diameter and ≥1 mm to the edge. Silkscreen needs line width ≥0.15 mm, text height ≥1.0 mm, and 0.15 mm pad-to-silk. — [JLCPCB capabilities](https://jlcpcb.com/capabilities/pcb-capabilities)

**Impedance control and materials**
- Impedance tolerance is "±10%" as standard, with "±5%" available on request. Listed FR-4 Dk values: 7628 = 4.4, 3313 = 4.1, 2116 = 4.16 (2-layer: 4.5). — [JLCPCB capabilities](https://jlcpcb.com/capabilities/pcb-capabilities)

**Project values (from the exports and brief)**
- Clearance rules:
  - `CLR_GENERAL_020` 0.20 mm; `CLR_POWER_025` and `CLR_ANALOG_025` 0.25 mm.
  - In-component pad–pad 0.10 mm for U_MCU1, UP1, UP2, UP4 and J_FPC1–5.
  - Pad–pad 0.125 mm for C_ADC1–5.
  - Local track–pad 0.15–0.20 mm and track–track 0.175 mm.
  - GND via to U_MCU1-31 pad 0.175 mm.
- Width rules: min 0.15 mm on all classes; preferred SPI 0.18 mm and POWER 0.9 mm (max 3 mm).
- Vias: `VIA_STD_060_030` pad 0.6/hole 0.3 (priority 1, All). The default `RoutingVias` 1.27/0.7112 is still present at priority 2.
- Board edge: `EDGE_050_GENERAL_PROVISIONAL` BOARD_EDGE_GAP = **0.254 mm**.
- Mask: `MinimumSolderMaskSliver` 0.1 mm; only one `SolderMaskExpansion` rule, **+0.05 mm, scope All**.
- Paste: `PasteMaskExpansion` 0.
- Other: `HoleToHoleClearance` is exported with no value. The default `Width` rule is 0.254/0.254/0.254 at priority 10 (All).
- Source: [RULES.txt](file:///C:/Users/PMLS/Desktop/emg-saw/hardware/pcb_layout_2026-09-23_drl/evidence/NATIVE_FINAL_20260924T015854610Z/RULES.txt)
- The brief sets starting targets: "copper-to-routed-edge setback at 0.50 mm", via 0.60/0.30 with 0.45/0.20 "only for justified dense escape and verified fabrication", and fine-pitch exceptions "around 0.10–0.125 mm only if supported by actual fabrication". — [layout brief §7](file:///C:/Users/PMLS/Desktop/emg-saw/hardware/pcb_layout_2026-09-16/Documentation/EMG_Main_PCB_Layout_Master_Prompt_2026-09-16.md)

**Values JLC lists differently between pages**
- POFV/filled-via hole range:
  - 0.15–0.55 mm on the [capabilities page](https://jlcpcb.com/capabilities/pcb-capabilities)
  - 0.2–0.5 mm in the [2022 POFV news](https://jlcpcb.com/news/free-via-in-pad-6-20-layer-pcbs-pofv)
  - "not larger than 0.5 mm" in the [via-covering article](https://jlcpcb.com/help/article/pcb-via-covering)
- Within the capabilities page, "SMD pad to pad 0.15 mm" sits alongside "pad to track 0.1 mm" and "min spacing 0.09 mm". JLC does not explain why pads are held to a larger gap than tracks. — [JLCPCB capabilities](https://jlcpcb.com/capabilities/pcb-capabilities)

### Inferences
Project rule vs JLC limit (my comparison of the values cited above):

| Item | Project value | JLC limit | Verdict |
|---|---|---|---|
| Min track | 0.15 mm | 0.09 mm | Project is looser (safe, 0.06 mm margin) |
| General / power-analog clearance | 0.20 / 0.25 mm | 0.09 mm | Looser (safe) |
| Local track–pad 0.15, track–track 0.175 | — | pad–track 0.10, spacing 0.09 | OK |
| In-footprint pad–pad 0.10 mm (MCU, UP1/2/4, FPC) and 0.125 mm (C_ADCx) | 0.10–0.125 mm | "SMD pad to pad 0.15 mm" | **Tighter than JLC's stated pad–pad value** (above 0.09 spacing). Acceptable only as manufacturer-footprint geometry; JLC PCBA lists 0.35 mm IC pitch, so such gaps are built routinely. Flag for DFM review. |
| Via 0.6/0.3 | ring 0.15 mm | ≥0.05 (0.075 preferred); surcharge only for 0.15 mm holes, or 0.2/0.25 mm holes with dia <0.45 | OK, no surcharge |
| Via 0.45/0.2 (exposed pads) | ring 0.125 mm | surcharge if 0.2 mm hole with dia **<0.45** | OK **exactly at threshold**. Do not shrink the pad below 0.45 mm. |
| Via hole–track | ≥0.35 mm hole–track (0.2 rule from 0.6 pad) | 0.2 mm from hole | OK |
| GND via to MCU pad 0.175 mm | hole–pad ≈0.325 mm | via hole–track 0.2 | OK for tented/open. **Not** ink-pluggable (<0.35 mm from pad); a filled via needs ≥0.35 mm to other mask openings |
| Hole-to-hole | not exported | 0.2 mm (vias), 0.45 mm (PTH pads) | **Verify the Altium value** |
| Copper to edge | **0.254 mm** (rule named "050"; brief intends 0.50) | routed ≥0.2, V-cut ≥0.4 | Passes a routed edge only. **Fails if the board is V-cut panelised** (likely for Standard PCBA, see Q5). Set to 0.50 mm as the brief intends. |
| Mask sliver | 0.10 mm | 0.10 green, 0.13 black/white | At the limit (green); fails for black/white mask |
| Mask expansion | +0.05 mm all | "1:1"; dam ≥0.10 | With +0.05 mm per side, pad gaps <0.20 mm leave a web <0.10 mm, which JLC will remove (ganged opening). That covers 0.10–0.15 mm pad gaps at fine pitch and the C_ADC pads. |
| Via tenting | "−0.35 mm expansion" per the task brief | tent holes ≤0.4 (≤0.5) mm, not guaranteed | Both 0.3 and 0.2 mm holes are tentable. **The rule is absent from RULES.txt**; confirm it exists or use via tenting properties. |
| Silk | silk–silk 0.254, silk–mask 0.254 | pad–silk 0.15, line ≥0.15, text ≥1.0 | OK (widths not exported) |
| Rule hygiene | default Width 0.254 min=max (priority 10); default RoutingVias 1.27/0.71 | — | Unclassed nets are forced to exactly 0.254 mm. Stale defaults should be cleaned up. |

- Inner-layer antipads: with 0.6 mm via pads kept on inner layers plus a 0.20–0.25 mm pour clearance, hole-to-copper is 0.35–0.40 mm, which clears JLC's 0.2 mm. If unused inner pads are removed and the pour clearance is measured from the hole, the 0.20 mm rule sits exactly at JLC's 0.2 mm minimum.
- The 0.10 mm in-component rules are only safe inside footprints whose copper came from the manufacturer's land pattern. They should never be allowed to apply to routed copper.

### Gaps
- ENIG Ni/Au thickness is not stated on the capabilities page.
- A separate inner-0.5 oz trace/space figure was not found. I assumed the multilayer 0.09/0.09 mm row applies.
- The exact meaning of "Soldermask expansion 1:1" and "keep at least 0.09 mm clearance" was not resolved from the extracted text.
- Whether JLC's order-form "Via Covering: Tented" option overrides the Gerber mask openings was not verified.
- Whether 4-layer impedance control itself carries a fee was not verified.
- The export does not include the Altium HoleToHole value, the silk-width values, or any via-tenting rule. These need to be read in Altium.

## Q2 — Which JLC 4-layer stack-up matches the Altium export

### Takeaway
The export matches **JLC04121H-3313** exactly: 1.2 mm nominal, outer 1 oz / inner 0.5 oz, pressed laminate 1.1642 mm, stack table below. JLC's live API still lists it (enabled, zero fee fields), but it is **not** JLC's default 1.2 mm 4-layer stack. The default is JLC04121H-7628, with 0.2104 mm prepreg and a 0.6 mm core, which would change every impedance on the board. The order must name JLC04121H-3313 explicitly. The Altium stack also carries a spurious 0.32 mm FR-4 dielectric below L4.

### Cited Findings
- Live JLC API response (queried 2026-09-24 with 4 layers, 1.2 mm, 1 oz outer, 0.5 oz inner) for **JLC04121H-3313**:
  - Layers: Top Cu 0.035 mm / prepreg "3313*1" 0.09940 mm / core "0.9mm H/HOZ with copper" = Cu 0.0152 + core 0.865 + Cu 0.0152 mm / prepreg "3313*1" 0.09940 mm / Bottom Cu 0.035 mm.
  - compressionThickness 1.1642 mm; enableFlag true; defaultFlag false; fixedFee 0; coefficient 0.
  - The default template (defaultFlag true) is **JLC04121H-7628**: Cu 0.035 / 7628 0.2104 / core 0.6 mm (Cu 0.0152 each side) / 7628 0.2104 / Cu 0.035, pressed 1.1212 mm.
  - Other enabled 1.2 mm templates: JLC04121H-1080 (1080 0.0764 mm, 0.865 core; non-zero fee fields 110/55), 1080A (non-zero fee fields 330/110), 1080B, 2116A, 2116B, 7628A (non-zero fee fields 330/110).
  — [JLC impedance-template API endpoint](https://cart.jlcpcb.com/api/overseas-shop-cart/v1/shoppingCart/getImpedanceTemplateSettings) (POST `{"cuprumThickness":1,"insideCuprumThickness":0.5,"stencilLayer":4,"stencilPly":1.2}`). I found the endpoint in [gsuberland/jlcpcb_autogenerated_stackups `generate_stackups.linq`](https://github.com/gsuberland/jlcpcb_autogenerated_stackups).
- A third-party archive of the same API (last updated 2025-05-09) has the identical JLC04121H-3313 table. Its normalised file assigns this core **Dk 4.43** from Nan Ya NP-155F datasheet data, not JLC data. — [gsuberland/jlcpcb_autogenerated_stackups](https://github.com/gsuberland/jlcpcb_autogenerated_stackups)
- JLC's stack-up page gives prepreg Dk 7628 = 4.4, 3313 = 4.1, 1080 = 3.91, 2116 = 4.16, and **core Dk 4.6**. Solder mask is 1.2 mil above substrate, 0.6 mil above trace, 1.2 mil between traces, Er 3.8. Copper options are outer 1/2 oz and inner 0.5/1/2 oz. The page defaults to the 1.6 mm JLC04161H family, which includes JLC04161H-3313. — [JLCPCB, "Controlled Impedance PCB Layer Stackup"](https://jlcpcb.com/impedance)
- JLC's impedance-calculator guide (last updated 2026-09-16) makes these modelling assumptions:
  - Nan Ya NP-155F material for 4–8 layers.
  - Copper thickness 1.6 mil for outer 1 oz, 0.6 mil for inner 0.5 oz, 1.2 mil for inner 1 oz.
  - Trapezoidal traces: "Trace top width – Trace base width – 0.7 mil".
  - Mask 1.2/0.6/1.2 mil, Er 3.8.
  — [JLCPCB help, "User Guide to the JLCPCB Impedance Calculator"](https://jlcpcb.com/help/article/User-Guide-to-the-JLCPCB-Impedance-Calculator)
- Finished-thickness tolerance is ±10% for boards ≥1.0 mm, i.e. 1.08–1.32 mm for 1.2 mm. — [JLCPCB capabilities](https://jlcpcb.com/capabilities/pcb-capabilities)
- The project export lists: L1 0.035 / JLC3313 prepreg 0.0994 Dk 4.1 / L2 GND 0.0152 / JLC core 0.865 Dk 4.6 / L3 "POWER SIGNAL" 0.0152 / JLC3313 prepreg 0.0994 Dk 4.1 / L4 BOTTOM GND 0.035. **Then an extra `DIELECTRIC|FR-4|MM=0.32004|DK=4.8` below L4.** — [STACK.txt](file:///C:/Users/PMLS/Desktop/emg-saw/hardware/pcb_layout_2026-09-23_drl/evidence/NATIVE_FINAL_20260924T015854610Z/STACK.txt)
- The brief requires recording "the actual selected JLCPCB or chosen fabricator stack and tolerances" and says "L3 signals must not depend on a fragmented L4 return". — [layout brief §5–6](file:///C:/Users/PMLS/Desktop/emg-saw/hardware/pcb_layout_2026-09-16/Documentation/EMG_Main_PCB_Layout_Master_Prompt_2026-09-16.md)

### Inferences
- The layer table is 0.035 + 0.0994 + 0.0152 + 0.865 + 0.0152 + 0.0994 + 0.035 = 1.1642 mm. This equals JLC's pressed thickness and the export's ≈1.16 mm. The nominal 1.2 mm finished board includes mask and plating.
- **Discrepancies:**
  - The extra 0.32 mm FR-4 layer under L4 does not exist in JLC04121H-3313. It makes Altium's stack about 1.48 mm, which distorts via length, 3D and drill reports. It has little effect on L1–L3 impedance. Remove it, or replace it with a solder-mask layer of about 0.015–0.03 mm at Er 3.8.
  - The export has no solder-mask layers, so Altium's impedance solver would report uncoated values, about 3 Ω high (see Q3).
  - Outer copper appears as 0.035 mm in JLC's stack table but 1.6 mil (0.0406 mm) in JLC's calculator. The effect on 50 Ω width is about 0.003 mm (Q3).
  - Core Dk is 4.6 on JLC's page but 4.43 in the third-party normalised data. The export's 4.6 matches JLC.
- Geometric consequence: L1 is 0.0994 mm above L2, which gives the tight L1–L2 coupling the brief asks for. **L3 is 0.0994 mm from L4 but 0.865 mm from L2, so L4 is L3's real reference.** Any L4 void, slot or split under an L3 signal breaks its impedance (Q3: about 112–119 Ω over a voided L4).
- The inner planes and L3 copper are 15.2 µm (half of outer). L3 power routing therefore has about 2.3× the sheet resistance of L1 (Q4).
- If an order leaves "Specified stackup" at the default, the fab builds JLC04121H-7628. A 0.161 mm L1 line becomes about 71.5 Ω and the 50 Ω width becomes about 0.357 mm (my field-solver results, Q3).

### Gaps
- JLC's API returns no per-layer Dk, so the core Dk (4.6 per JLC's page vs 4.43 NP-155F-derived) cannot be confirmed from the API.
- The currency/meaning of the fee fields (fixedFee/coefficient) is undocumented. "Zero fee" for 3313 is inferred from the field values.
- The JLC stack page's 1.2 mm view could not be rendered by the fetch tool (it showed the 1.6 mm family), so the stack was confirmed through the API.

## Q3 — 50 Ω single-ended geometry on JLC04121H-3313

### Takeaway
My 2D field-solver calculations with JLC's published parameters give these 50 Ω widths:
- **L1 microstrip over L2: ≈0.16 mm with solder mask** (0.161 mm with 35 µm copper, 0.158 mm with JLC's 1.6 mil), or 0.18 mm without mask.
- **L1 with coplanar GND pour: ≈0.145/0.153/0.156 mm at 0.15/0.20/0.25 mm gaps.**
- **L3 referenced to L4: ≈0.136 mm** (0.123–0.132 mm with a coplanar L3 GND pour).

The project's 0.18 mm SPI width gives ≈47 Ω on L1 (inside ±10%) but ≈43.5 Ω on L3 (13% low). On L3, use about 0.14 mm (49 Ω, needs a scoped exception to the 0.15 mm minimum) or 0.15 mm (47.7 Ω). Without impedance control, JLC's ±20% width tolerance alone spreads any 50 Ω design to about 42–60 Ω.

### Cited Findings
- JLC inputs used:
  - 3313 prepreg Dk 4.1 and 0.0994 mm; core Dk 4.6 and 0.865 mm; inner Cu 0.0152 mm; outer Cu 0.035 mm — [JLC stack page](https://jlcpcb.com/impedance) and the [JLC API](https://cart.jlcpcb.com/api/overseas-shop-cart/v1/shoppingCart/getImpedanceTemplateSettings)
  - Mask 1.2 mil over substrate and 0.6 mil over trace, Er 3.8; trapezoid top = base − 0.7 mil; outer Cu 1.6 mil in the calculator — [JLC calculator guide](https://jlcpcb.com/help/article/User-Guide-to-the-JLCPCB-Impedance-Calculator)
- JLC's calculator offers "Coplanar Single Ended", "Coplanar Differential Pair", "Single Ended (Non-coplanar)" and "Differential Pair (Non-coplanar)" models. — [JLC calculator guide](https://jlcpcb.com/help/article/User-Guide-to-the-JLCPCB-Impedance-Calculator)
- Fab tolerances: impedance ±10% standard (±5% on request); track width ±20%; board thickness ±10%. — [JLCPCB capabilities](https://jlcpcb.com/capabilities/pcb-capabilities)
- Closed-form cross-check model: Hammerstad & Jensen microstrip equations with finite-thickness correction — [E. Hammerstad, Ø. Jensen, "Accurate Models for Microstrip Computer-Aided Design," IEEE MTT-S 1980](https://doi.org/10.1109/MWSYM.1980.1124303)
- The brief says SPI width should come "from approximately 50-ohm profile", with the existing 22 Ω series resistors kept and "no 50-ohm shunt". — [layout brief §7/§11](file:///C:/Users/PMLS/Desktop/emg-saw/hardware/pcb_layout_2026-09-16/Documentation/EMG_Main_PCB_Layout_Master_Prompt_2026-09-16.md)

### Inferences
**Method.** I used my own quasi-static 2D finite-volume Laplace solver on a non-uniform grid (2 µm cells near the conductors), with Z0 = 1/(c·√(C·C_air)).
- Validation against Hammerstad–Jensen for an uncoated rectangular trace (h 0.0994 mm, Er 4.1, t 35 µm): 60.17 vs 60.17 Ω at w 0.12 mm, 49.28 vs 49.22 Ω at 0.18 mm, and 40.87 vs 40.80 Ω at 0.25 mm. Agreement is within 0.2%.
- Assumptions:
  - JLC trapezoid (top narrower by 0.7 mil).
  - Conformal mask 30.5 µm on the laminate and 15.2 µm on copper, Er 3.8.
  - Coplanar pours are 1.2 mm wide and ideally stitched to L2.
  - The L3 narrow face points toward L4, and prepreg resin (Dk 4.1) fills beside L3 traces.
  - Lossless and quasi-static, which is adequate at tens of MHz.

**L1 microstrip over L2 (h 0.0994 mm):**

| Case | 50 Ω width (mm) | Z at 0.10 / 0.127 / 0.15 / 0.16 / 0.18 / 0.20 / 0.25 / 0.30 mm |
|---|---|---|
| Uncoated, t 35 µm | **0.180** | 66.5 / 59.7 / 55.0 / 53.2 / 50.0 / 47.1 / 41.3 / 36.9 |
| Mask-coated, t 35 µm | **0.161** | 61.6 / 55.8 / 51.7 / 50.2 / 47.3 / 44.8 / 39.5 / 35.4 |
| Uncoated, t 40.6 µm (JLC calc) | 0.177 | 65.7 / 59.1 / 54.5 / 52.7 / 49.6 / 46.8 / 41.1 / 36.6 |
| Mask-coated, t 40.6 µm | 0.158 | 60.9 / 55.2 / 51.2 / 49.7 / 46.9 / 44.4 / 39.2 / 35.2 |

- Effective permittivity is 3.30 coated (6.06 ps/mm) and 2.97 uncoated (5.75 ps/mm).

**L1 coplanar with ground (coated, t 35 µm):**

| Gap to GND pour | 50 Ω width | Z at w = 0.15 / 0.18 / 0.20 mm |
|---|---|---|
| 0.15 mm | 0.145 mm | 49.2 / 45.1 / 42.8 |
| 0.20 mm | 0.153 mm | 50.4 / 46.1 / 43.7 |
| 0.25 mm | 0.156 mm | 51.0 / 46.6 / 44.1 |
| 0.30 mm | 0.158 mm | 51.3 / 46.9 / 44.4 |

- With the 0.2 mm general clearance to a stitched GND pour, **0.15 mm on L1 is about 50 Ω**. Pours pull Z down by only 0.5–2 Ω because h (0.1 mm) is much smaller than the gap.

**L3 (L4 at 0.0994 mm below, prepreg Dk 4.1; L2 at 0.865 mm above, core Dk 4.6; t 15.2 µm):**
- 50 Ω width is **0.136 mm**. Effective permittivity is 4.25 (6.88 ps/mm).
- Z at 0.09 / 0.10 / 0.11 / 0.127 / 0.14 / 0.15 / 0.18 / 0.20 / 0.25 mm = 59.9 / 57.4 / 55.1 / 51.7 / 49.3 / 47.7 / 43.5 / 41.1 / 36.2 Ω.
- With a coplanar GND pour on L3 at gaps 0.15 / 0.20 / 0.25 mm, the 50 Ω width is 0.123 / 0.129 / 0.132 mm.
- **With L4 voided under the trace** (only L2 as reference), Z is 119 Ω at 0.15 mm and 112 Ω at 0.20 mm. Continuous L4 GND under the L3 SPI corridor is mandatory, consistent with the brief.

**Sensitivity (L1 coated, nominal 0.161 mm = 50.0 Ω):**
- Width −20% gives 55.5 Ω; +20% gives 45.6 Ω.
- Prepreg −10% gives 47.0 Ω; +10% gives 52.8 Ω.
- Dk 3.9 gives 51.0 Ω; Dk 4.3 gives 49.1 Ω.
- No mask gives **53.0 Ω (mask ≈ −3 Ω)**; double mask thickness gives 48.7 Ω.
- Stacked corners (w ±20%, h ±10%, Dk 3.9–4.3): 41.9–59.5 Ω for 0.161 mm and 39.4–56.6 Ω for 0.18 mm.
- For L3 at 0.136 mm the corners are 42.4–59.1 Ω (core Dk 4.4–4.8).
- Ordering "impedance control" makes JLC hold ±10% (±5% on request) by adjusting width. Without it, the ±20% width tolerance dominates.

**Recommendations for the SPI class:**
- L1: 0.16 mm microstrip, or 0.15 mm with a stitched GND pour at ≥0.2 mm.
- L3: 0.14 mm, which needs a scoped width exception because the global minimum is 0.15 mm. Alternatively accept 0.15 mm (47.7 Ω, −4.6%).
- The current preferred 0.18 mm is fine on L1 (47.3 Ω) but low on L3 (43.5 Ω).

**Default-stack risk.** On JLC04121H-7628 (0.2104 mm 7628, Dk 4.4), L1 coated 0.161 / 0.18 mm gives 71.5 / 68.5 Ω and 50 Ω needs 0.357 mm. L3 at 0.136 / 0.15 mm gives 65.2 / 62.8 Ω. The stack must be ordered as JLC04121H-3313.

**Delay.** At 6–7 ps/mm, a 50 mm SPI route has a one-way delay of about 0.3–0.35 ns.

### Gaps
- JLC's own calculator output for JLC04121H-3313 could not be retrieved; the calculator is interactive and no calculation API was found. Cross-check these widths in JLC's calculator or in Altium's Layer Stack Manager, with solder mask added, before locking the SPI rule.
- IPC-2141A closed forms were not used or retrieved (the standard is paywalled). The field solver was cross-checked with Hammerstad–Jensen instead.
- How JLC models inner-layer trapezoid orientation and resin-rich Dk beside L3 traces is not documented. I assumed prepreg Dk 4.1; a lower resin-pocket Dk would raise the L3 Z slightly.

## Q4 — Current capacity of tracks and vias (IPC-2152 basis), voltage drop, multiple vias

### Takeaway
At the 0.6 A 3.3 V planning load, temperature rise is not the constraint:
- The conservative generic IPC-2152 chart needs only about 0.11 mm on 35 µm L1 or 0.26 mm on 15.2 µm L3 for a 10 °C rise.
- Voltage drop and converter-loop inductance should size the 0.9 mm power corridors.
- For a charger path at 1.5 A, use ≥0.6 mm (L1, 10 °C) or ≥1.4 mm (L3, 10 °C). At 2 A, use ≥1.0 mm on L1 or ≥2.3 mm on L3.

A 0.3 mm via with JLC's 18 µm average plating has a barrel of about 0.016–0.018 mm², about 1.15–1.3 mΩ, and roughly 1.3–1.4 A (10 °C) or 1.8–1.9 A (20 °C) by the barrel-area method. Use 2–4 vias per current transition.

### Cited Findings
- IPC-2152 generic-chart curve fit: A[mil²] = (117.555·ΔT^−0.913 + 1.15) · I^(0.84·ΔT^−0.108 + 1.159), with I the RMS current in A and ΔT in °C. It checks within 3% of IPC data (10 A/20 °C: IPC 500 mil², fit 513.1). — [L. Rozenblat, "PCB Trace Width Calculator and Equations" (smps.us)](https://www.smps.us/pcb-calculator.html)
- The generic IPC-2152 charts represent "polyimide boards 0.070" thick with 3 ounce copper in still air". Modifiers exist for copper weight, board thickness, plane area and distance to plane.
  - "The old PCB design standard overstated current carrying capacity of external tracks."
  - For internal tracks, "the legacy recommendations … happened to be conservative".
  - The new standard suggests "the same copper size for all board's layers".
  — [smps.us](https://www.smps.us/pcb-calculator.html)
- JLC via plating: "Average Hole Plating Thickness: 18μm". — [JLCPCB capabilities](https://jlcpcb.com/capabilities/pcb-capabilities)
- Brooks & Adam measurements (Signal Integrity Journal, summarised by Altium):
  - "thin traces tend to run hotter than the via connected to them, with a temperature difference of only a few °C". With wide (200 mil) traces the via is the warmer part by a few °C.
  - "The rules for sizing traces are often applied to sizing vias."
  - A "0.5 A rule of thumb sometimes seen on forums" is overly conservative. With "a less-conservative limit of 1 A per via … to supply 5 A … 5 large vias with thick plating should be fine".
  — [Z. Peterson, Altium, "PCB Via Current-Carrying Capacity: Is My PCB Too Hot?" (updated Sept 2025)](https://resources.altium.com/p/pcb-current-carrying-capacity-how-hot-too-hot)
- The brief says: "Use multiple power vias for current paths as calculated; do not assign a universal amperage rating to a via". It also says LX routing "is not sized merely from the average radio current" and that 0.6 A is "a planning case, not a guaranteed maximum". — [layout brief §12–13](file:///C:/Users/PMLS/Desktop/emg-saw/hardware/pcb_layout_2026-09-16/Documentation/EMG_Main_PCB_Layout_Master_Prompt_2026-09-16.md)

### Inferences
**Track widths** from the smps.us IPC-2152 generic fit (no modifiers, so conservative), width = area ÷ physical copper thickness. Thicknesses: 35 µm = 1.378 mil (L1/L4 outer); 17.5 µm (nominal 0.5 oz); 15.2 µm = 0.598 mil (JLC inner 0.5 oz, L2/L3).

| ΔT | I (A) | Area (mil²) | 35 µm outer | 17.5 µm | 15.2 µm inner |
|---|---|---|---|---|---|
| 10 °C | 0.5 | 4.4 | 0.08 mm | 0.16 mm | 0.19 mm |
| 10 °C | 1.0 | 15.5 | 0.29 mm | 0.57 mm | 0.66 mm |
| 10 °C | 1.5 | 32.4 | 0.60 mm | 1.19 mm | 1.37 mm |
| 10 °C | 2.0 | 54.5 | 1.01 mm | 2.01 mm | 2.32 mm |
| 20 °C | 0.5 | 2.6 | 0.05 mm | 0.10 mm | 0.11 mm |
| 20 °C | 1.0 | 8.8 | 0.16 mm | 0.32 mm | 0.37 mm |
| 20 °C | 1.5 | 18.0 | 0.33 mm | 0.66 mm | 0.76 mm |
| 20 °C | 2.0 | 29.9 | 0.55 mm | 1.10 mm | 1.27 mm |

- Comparison with the older IPC-2221 formula (I = k·ΔT^0.44·A^0.725, with k = 0.048 external / 0.024 internal as reproduced by online calculators; not fetched in this session):

  | ΔT | Outer 35 µm, 0.5 / 1 / 1.5 / 2 A | Inner 15.2 µm, 0.5 / 1 / 1.5 / 2 A |
  |---|---|---|
  | 10 °C | 0.12 / 0.30 / 0.53 / 0.78 mm | 0.69 / 1.80 / 3.15 / 4.68 mm |
  | 20 °C | 0.08 / 0.20 / 0.35 / 0.51 mm | 0.45 / 1.18 / 2.07 / 3.07 mm |

  IPC-2221's internal widths are about 2–3.7× wider than IPC-2152's, matching smps.us's point that the legacy internal rule was conservative.
- **Reverse check of project widths** (generic fit):
  - 0.9 mm EMG_POWER on L1: about 1.9 A at 10 °C and 2.6 A at 20 °C. The same width on L3: about 1.2 A at 10 °C and 1.65 A at 20 °C.
  - The 0.15 mm minimum-width neck on L1: about 0.70 A at 10 °C. On L3: about 0.44 A at 10 °C. **A 0.15 mm neck on L3 carrying the 0.6 A rail exceeds 10 °C by the generic chart.** Short necks are thermally benign, but review any long L3 power necks.
  - The planning 0.6 A needs about 6.1 mil² (0.11 mm on L1, 0.26 mm on L3) at 10 °C.
- These widths are conservative. The generic chart assumes a 1.78 mm polyimide board with no planes, while this board has solid GND copper 0.1 mm from L1 and L3. IPC-2152 plane modifiers would lower the rise substantially, but the modifier charts were not available here.
- **Voltage drop** (ρ = 1.724 µΩ·cm at 20 °C, annealed copper; an assumption): sheet resistance is 0.493 mΩ/□ for 35 µm and 1.134 mΩ/□ for 15.2 µm. At 0.6 A:
  - 20 mm × 0.9 mm on L1 → 10.9 mΩ, 6.6 mV.
  - 20 mm × 0.5 mm on L1 → 19.7 mΩ, 11.8 mV.
  - 20 mm × 0.9 mm on L3 → 25.2 mΩ, 15.1 mV.
  - 5 mm × 0.3 mm neck on L1 → 8.2 mΩ, 4.9 mV.
  - Budget copper by millivolts, which dominates well before heating does.
- **Via barrels** (length 1.2 mm; area range spans finished-hole-equals-nominal vs drilled-hole-equals-nominal). "Barrel-area method" means treating the barrel as a conductor of equal area in the IPC-2152 generic fit, the approach Altium describes; the IPC-2221 external formula gives similar values (e.g. 1.35–1.48 A at 10 °C for 0.3 mm/18 µm).

  | Via | Barrel area | R (full barrel) | I at 10 °C | I at 20 °C |
  |---|---|---|---|---|
  | 0.3 mm hole, 18 µm (JLC average) | 0.0159–0.0180 mm² (24.7–27.9 mil²) | 1.15–1.30 mΩ | 1.29–1.38 A | 1.80–1.92 A |
  | 0.3 mm hole, 20 µm | — | 1.03–1.18 mΩ | 1.36–1.47 A | — |
  | 0.3 mm hole, 25 µm | — | 0.81–0.96 mΩ | — | — |
  | 0.2 mm hole, 18 µm | 0.0103–0.0123 mm² | 1.68–2.01 mΩ | 1.02–1.12 A | 1.40–1.55 A |

  Per Brooks/Adam, the attached thin traces, not the via, are usually the hot spot. An L1→L2 or L1→L3 transition uses only part of the barrel length, so its resistance is lower.
- **Guidance for converter and charger paths:**
  - For 1.5 A paths (USB-C VBUS → charger IN, charger OUT/BAT, TPS631000 VIN/VOUT), 2 × 0.3 mm vias meet the 10 °C barrel limit.
  - Use **3–4 vias per layer change** (≈0.3–0.4 mΩ combined), roughly ≤0.5 A per via. This gives margin for the unverified converter peak currents, lower loop inductance, and plating-void redundancy.
  - For 0.6 A 3V3 transitions, use ≥2 vias.
  - Keep switching-loop (LX, CIN/COUT) currents on one layer where possible, as the brief prefers.
  - The 0.2 mm in-pad vias are thermal paths. Do not count on them for current.

### Gaps
- IPC-2152 itself (charts and modifiers) and the Saturn PCB Toolkit documentation were not retrieved. Plane, board-thickness and copper-weight modifiers were therefore not applied.
- The primary Brooks & Adam Signal Integrity Journal article was not fetched; the Altium summary was used.
- Whether JLC's 18 µm average plating meets IPC-6012 Class 2 averages was not verified.
- Charger ILIM maximum (BQ24072T) and TPS631000 peak switch/inductor currents were not verified in this session. Size LX and VIN/VOUT copper from the datasheets' peak currents, not the average load.
- No source was found for a JLC-specific current chart.

## Q5 — JLC assembly (PCBA) rules that affect routing: via-in-pad, paste, fiducials, edges

### Takeaway
Size limits force a choice between the two JLC assembly tiers:
- **Standard PCBA** handles 0.35 mm-pitch parts and 0201s, but it needs a single board of at least 70 × 70 mm (this board's 45 mm side is too small) and it requires edge rails and fiducials.
- **Economic PCBA** accepts an 80 × 45 mm single board with no rails or fiducials, but only down to 0.4 mm pitch and 0402.

Standard PCBA therefore means panelising with 5 mm rails. If that panel is V-cut, copper must stay ≥0.4 mm from the V-cut edge, which the current 0.254 mm edge rule fails.

For vias in the exposed pads:
- JLC cannot ink-plug vias in pads or within 0.35 mm of pads.
- Filled-and-capped (POFV) is available on 4-layer boards but is charged.
- JLC's assembly page states no mandatory rule, so choose between open vias (solder-wicking risk), selective filling identified by the unique 0.2 mm diameter, or paid POFV.

### Cited Findings
- **Board size:** single-board Standard PCBA 70 × 70 to 460 × 500 mm; Economic 10 × 10 to 470 × 500 mm. Panelised (both tiers) 10 × 10 to 250 × 250 mm, 250 × 250 mm recommended maximum. — [JLCPCB, "PCB Assembly Capabilities"](https://jlcpcb.com/capabilities/pcb-assembly-capabilities)
- **Rails and fiducials:** edge rails are required for Standard and not necessary for Economic. Fiducials are "Necessary" for Standard and "Not necessary" for Economic. — [JLCPCB PCBA capabilities](https://jlcpcb.com/capabilities/pcb-assembly-capabilities)
- **Pitch and package:** minimum IC pin spacing is 0.35 mm (Standard) and 0.4 mm (Economic). Minimum BGA pitch is 0.3 mm (Standard) and 0.5 mm (Economic). Minimum package is 0201 (Standard) and 0402 (Economic). — [JLCPCB PCBA capabilities](https://jlcpcb.com/capabilities/pcb-assembly-capabilities)
- **Page silences:** the PCBA capabilities page states no via-in-pad, thermal-pad-via or stencil/aperture rules. — [JLCPCB PCBA capabilities](https://jlcpcb.com/capabilities/pcb-assembly-capabilities)
- **Process edges:** recommended are "5 mm process edges, 2 mm tooling holes, and 1 mm fiducials placed 3.85 mm from the panel edge". With too-narrow process edges, components near the edge "might collide with the guide rails". — [JLCPCB help, "Specifications for Adding Process Edges and Positioning Holes" (updated 2026-09-09)](https://jlcpcb.com/help/article/specifications-for-adding-process-edges-and-positioning-holes)
- **Via-in-pad plugging:** vias in pads, and vias closer than 0.35 mm to a pad, "cannot be plugged with ink"; they can be epoxy- or copper-filled. Plugging can be specified per via diameter. — [JLCPCB via-covering article](https://jlcpcb.com/help/article/pcb-via-covering)
- **Solder wicking:** for regular vias in pads, "during reflow soldering the solder can be wicked into the hole, leaving too little on the surface to secure the component". POFV fixes this and is charged on 4-layer boards (hole 0.2–0.5 mm, ring ≥0.05 mm with 0.075 mm preferred, ≥0.45 mm from PTH/NPTH). — [JLCPCB POFV news (2022-11-02)](https://jlcpcb.com/news/free-via-in-pad-6-20-layer-pcbs-pofv)
- **Filled-via spacing:** filled vias need ≥0.35 mm clearance from other soldermask openings; epoxy or copper-paste fill supports 0.15–0.55 mm vias. — [JLCPCB capabilities](https://jlcpcb.com/capabilities/pcb-capabilities)
- The brief requires "a manufacturer/assembler-qualified filled/capped or approved tented/plugged/stencil arrangement" for the ST67/BQ thermal lands. It notes "tenting is not equivalent to filling", and says ordinary vias "should not be open via-in-pad under small SMT components". It also cites "the ST multi-via central-land recommendation, commonly five vias per land". — [layout brief §10/§13](file:///C:/Users/PMLS/Desktop/emg-saw/hardware/pcb_layout_2026-09-16/Documentation/EMG_Main_PCB_Layout_Master_Prompt_2026-09-16.md)
- Project paste rule `PasteMaskExpansion` = 0 (paste openings equal pads, no windowpane rule). — [RULES.txt](file:///C:/Users/PMLS/Desktop/emg-saw/hardware/pcb_layout_2026-09-23_drl/evidence/NATIVE_FINAL_20260924T015854610Z/RULES.txt)

### Inferences
- **Tier choice.** The task context mentions 0.35 mm-pitch parts, which only Standard PCBA places. Standard PCBA needs a ≥70 × 70 mm single board or a panel with rails and fiducials, so plan an assembly panel with 5 mm rails, 1 mm fiducials 3.85 mm from the panel edge, and 2 mm tooling holes.
  - V-cut panel: raise copper-to-edge to ≥0.4 mm (0.5 mm per the brief). The exported 0.254 mm fails.
  - Routed tabs/mouse-bites: 0.2 mm is the fab minimum, but breakout damage argues for the brief's 0.5 mm.
  - Economic PCBA is possible only if every part is ≥0.4 mm pitch and ≥0402.
- **Exposed-pad vias.** Only the in-pad vias use a 0.2 mm hole, so JLC can identify them by diameter and fill only those. Three routes:
  - **(a) Paid POFV.** The ring (0.125 mm) is fine; keep ≥0.45 mm to any PTH/NPTH.
  - **(b) Open 0.2 mm vias.** Pair them with a windowpane paste aperture that avoids the via openings. This accepts some wicking and voiding, which JLC warns of.
  - **(c) Mask-tent from the bottom only.** JLC does not guarantee tents, and the brief says tenting is not filling.
  - Whichever route is chosen must be written into the order notes, because nothing in JLC's assembly page enforces it.
- **Paste.** With `PasteMaskExpansion` 0, the ST67 centre lands and the BQ24072T thermal pad would receive 100% paste openings. Add footprint-level segmented paste (windowpane) regions for large exposed pads per the device datasheets; JLC's pages give no stencil rule to rely on.
- **Near-pad vias.** Tented vias ≤0.35 mm from pads (e.g. the 0.175 mm GND via by U_MCU1-31) cannot be ink-plugged. Leave them tented or open, not "plugged".

### Gaps
- JLC's stencil thickness and its automatic handling of exposed-pad apertures were not found on the fetched pages.
- These search-result numbers were not verified by fetching the source page (the JLC edge-rails article): fiducial ≥3.35 mm from the board edge, rails ≥5 mm, component body ≥2.5 mm from the board edge. Treat them as unconfirmed.
- A snippet stating "JLCPCB SMT fully supports 0.4mm pitch QFNs, Via-in-Pad, and AXI" (JLC blog) was also not verified.
- Whether a single-board Standard PCBA order below 70 mm is auto-panelised by JLC or rejected was not verified.
- JLC's order-form behaviour when POFV is selected (all vias or only specified diameters) is only implied by the via-covering article's "specify which via diameters" wording.
- The actual pitch of the "0.35 mm-pitch" parts and any 0201 usage should be confirmed from the BOM; that decides between Standard and Economic PCBA.

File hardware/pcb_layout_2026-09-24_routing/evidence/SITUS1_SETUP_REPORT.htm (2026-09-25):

Errors and Warnings - 80 Errors 4 Warnings 1 Hint

Error : Pad J_FPC5-3 Appears to be unroutable. Violation against Rule - CLR_BK13_ESCAPE_J_FPC5 Clearance Constraint (Gap=0.13mm) (InRegionAbsolute(2755.9055,409.4488,3035.4331,594.4882) And (InComponent('J_FPC5') Or InNet('3V0_ANA') Or InNet('GND') Or InNet('NetJ_FPC5_8') Or InNet('Va_5') Or InNet('Vb_5') Or InNet('Vc_5'))),(InRegionAbsolute(2755.9055,409.4488,3035.4331,594.4882) And (InComponent('J_FPC5') Or InNet('3V0_ANA') Or InNet('GND') Or InNet('NetJ_FPC5_8') Or InNet('Va_5') Or InNet('Vb_5') Or InNet('Vc_5'))) Detected.

Error : Pad J_FPC5-4 Appears to be unroutable. Violation against Rule - CLR_BK13_ESCAPE_J_FPC5 Clearance Constraint (Gap=0.13mm) (InRegionAbsolute(2755.9055,409.4488,3035.4331,594.4882) And (InComponent('J_FPC5') Or InNet('3V0_ANA') Or InNet('GND') Or InNet('NetJ_FPC5_8') Or InNet('Va_5') Or InNet('Vb_5') Or InNet('Vc_5'))),(InRegionAbsolute(2755.9055,409.4488,3035.4331,594.4882) And (InComponent('J_FPC5') Or InNet('3V0_ANA') Or InNet('GND') Or InNet('NetJ_FPC5_8') Or InNet('Va_5') Or InNet('Vb_5') Or InNet('Vc_5'))) Detected.

Error : Pad J_FPC5-5 Appears to be unroutable. Violation against Rule - CLR_BK13_ESCAPE_J_FPC5 Clearance Constraint (Gap=0.13mm) (InRegionAbsolute(2755.9055,409.4488,3035.4331,594.4882) And (InComponent('J_FPC5') Or InNet('3V0_ANA') Or InNet('GND') Or InNet('NetJ_FPC5_8') Or InNet('Va_5') Or InNet('Vb_5') Or InNet('Vc_5'))),(InRegionAbsolute(2755.9055,409.4488,3035.4331,594.4882) And (InComponent('J_FPC5') Or InNet('3V0_ANA') Or InNet('GND') Or InNet('NetJ_FPC5_8') Or InNet('Va_5') Or InNet('Vb_5') Or InNet('Vc_5'))) Detected.

Error : Pad J_FPC5-2 Appears to be unroutable. Violation against Rule - CLR_BK13_ESCAPE_J_FPC5 Clearance Constraint (Gap=0.13mm) (InRegionAbsolute(2755.9055,409.4488,3035.4331,594.4882) And (InComponent('J_FPC5') Or InNet('3V0_ANA') Or InNet('GND') Or InNet('NetJ_FPC5_8') Or InNet('Va_5') Or InNet('Vb_5') Or InNet('Vc_5'))),(InRegionAbsolute(2755.9055,409.4488,3035.4331,594.4882) And (InComponent('J_FPC5') Or InNet('3V0_ANA') Or InNet('GND') Or InNet('NetJ_FPC5_8') Or InNet('Va_5') Or InNet('Vb_5') Or InNet('Vc_5'))) Detected.

Error : Pad J_FPC5-1 Appears to be unroutable. Violation against Rule - CLR_BK13_ESCAPE_J_FPC5 Clearance Constraint (Gap=0.13mm) (InRegionAbsolute(2755.9055,409.4488,3035.4331,594.4882) And (InComponent('J_FPC5') Or InNet('3V0_ANA') Or InNet('GND') Or InNet('NetJ_FPC5_8') Or InNet('Va_5') Or InNet('Vb_5') Or InNet('Vc_5'))),(InRegionAbsolute(2755.9055,409.4488,3035.4331,594.4882) And (InComponent('J_FPC5') Or InNet('3V0_ANA') Or InNet('GND') Or InNet('NetJ_FPC5_8') Or InNet('Va_5') Or InNet('Vb_5') Or InNet('Vc_5'))) Detected.

Error : Pad J_FPC5-8 Appears to be unroutable. Violation against Rule - CLR_BK13_ESCAPE_J_FPC5 Clearance Constraint (Gap=0.13mm) (InRegionAbsolute(2755.9055,409.4488,3035.4331,594.4882) And (InComponent('J_FPC5') Or InNet('3V0_ANA') Or InNet('GND') Or InNet('NetJ_FPC5_8') Or InNet('Va_5') Or InNet('Vb_5') Or InNet('Vc_5'))),(InRegionAbsolute(2755.9055,409.4488,3035.4331,594.4882) And (InComponent('J_FPC5') Or InNet('3V0_ANA') Or InNet('GND') Or InNet('NetJ_FPC5_8') Or InNet('Va_5') Or InNet('Vb_5') Or InNet('Vc_5'))) Detected.

Error : Pad J_FPC5-9 Appears to be unroutable. Violation against Rule - CLR_BK13_ESCAPE_J_FPC5 Clearance Constraint (Gap=0.13mm) (InRegionAbsolute(2755.9055,409.4488,3035.4331,594.4882) And (InComponent('J_FPC5') Or InNet('3V0_ANA') Or InNet('GND') Or InNet('NetJ_FPC5_8') Or InNet('Va_5') Or InNet('Vb_5') Or InNet('Vc_5'))),(InRegionAbsolute(2755.9055,409.4488,3035.4331,594.4882) And (InComponent('J_FPC5') Or InNet('3V0_ANA') Or InNet('GND') Or InNet('NetJ_FPC5_8') Or InNet('Va_5') Or InNet('Vb_5') Or InNet('Vc_5'))) Detected.

Error : Pad J_FPC5-7 Appears to be unroutable. Violation against Rule - CLR_BK13_ESCAPE_J_FPC5 Clearance Constraint (Gap=0.13mm) (InRegionAbsolute(2755.9055,409.4488,3035.4331,594.4882) And (InComponent('J_FPC5') Or InNet('3V0_ANA') Or InNet('GND') Or InNet('NetJ_FPC5_8') Or InNet('Va_5') Or InNet('Vb_5') Or InNet('Vc_5'))),(InRegionAbsolute(2755.9055,409.4488,3035.4331,594.4882) And (InComponent('J_FPC5') Or InNet('3V0_ANA') Or InNet('GND') Or InNet('NetJ_FPC5_8') Or InNet('Va_5') Or InNet('Vb_5') Or InNet('Vc_5'))) Detected.

Error : Pad J_FPC5-6 Appears to be unroutable. Violation against Rule - CLR_BK13_ESCAPE_J_FPC5 Clearance Constraint (Gap=0.13mm) (InRegionAbsolute(2755.9055,409.4488,3035.4331,594.4882) And (InComponent('J_FPC5') Or InNet('3V0_ANA') Or InNet('GND') Or InNet('NetJ_FPC5_8') Or InNet('Va_5') Or InNet('Vb_5') Or InNet('Vc_5'))),(InRegionAbsolute(2755.9055,409.4488,3035.4331,594.4882) And (InComponent('J_FPC5') Or InNet('3V0_ANA') Or InNet('GND') Or InNet('NetJ_FPC5_8') Or InNet('Va_5') Or InNet('Vb_5') Or InNet('Vc_5'))) Detected.

Error : Pad J_FPC5-P1_2 Appears to be unroutable. Violation against Rule - CLR_BK13_ESCAPE_J_FPC5 Clearance Constraint (Gap=0.13mm) (InRegionAbsolute(2755.9055,409.4488,3035.4331,594.4882) And (InComponent('J_FPC5') Or InNet('3V0_ANA') Or InNet('GND') Or InNet('NetJ_FPC5_8') Or InNet('Va_5') Or InNet('Vb_5') Or InNet('Vc_5'))),(InRegionAbsolute(2755.9055,409.4488,3035.4331,594.4882) And (InComponent('J_FPC5') Or InNet('3V0_ANA') Or InNet('GND') Or InNet('NetJ_FPC5_8') Or InNet('Va_5') Or InNet('Vb_5') Or InNet('Vc_5'))) Detected.

Error : Pad J_FPC5-P1_1 Appears to be unroutable. Violation against Rule - CLR_BK13_ESCAPE_J_FPC5 Clearance Constraint (Gap=0.13mm) (InRegionAbsolute(2755.9055,409.4488,3035.4331,594.4882) And (InComponent('J_FPC5') Or InNet('3V0_ANA') Or InNet('GND') Or InNet('NetJ_FPC5_8') Or InNet('Va_5') Or InNet('Vb_5') Or InNet('Vc_5'))),(InRegionAbsolute(2755.9055,409.4488,3035.4331,594.4882) And (InComponent('J_FPC5') Or InNet('3V0_ANA') Or InNet('GND') Or InNet('NetJ_FPC5_8') Or InNet('Va_5') Or InNet('Vb_5') Or InNet('Vc_5'))) Detected.

Error : Pad J_FPC5-P2_1 Appears to be unroutable. Violation against Rule - CLR_BK13_ESCAPE_J_FPC5 Clearance Constraint (Gap=0.13mm) (InRegionAbsolute(2755.9055,409.4488,3035.4331,594.4882) And (InComponent('J_FPC5') Or InNet('3V0_ANA') Or InNet('GND') Or InNet('NetJ_FPC5_8') Or InNet('Va_5') Or InNet('Vb_5') Or InNet('Vc_5'))),(InRegionAbsolute(2755.9055,409.4488,3035.4331,594.4882) And (InComponent('J_FPC5') Or InNet('3V0_ANA') Or InNet('GND') Or InNet('NetJ_FPC5_8') Or InNet('Va_5') Or InNet('Vb_5') Or InNet('Vc_5'))) Detected.

Error : Pad J_FPC5-P2_2 Appears to be unroutable. Violation against Rule - CLR_BK13_ESCAPE_J_FPC5 Clearance Constraint (Gap=0.13mm) (InRegionAbsolute(2755.9055,409.4488,3035.4331,594.4882) And (InComponent('J_FPC5') Or InNet('3V0_ANA') Or InNet('GND') Or InNet('NetJ_FPC5_8') Or InNet('Va_5') Or InNet('Vb_5') Or InNet('Vc_5'))),(InRegionAbsolute(2755.9055,409.4488,3035.4331,594.4882) And (InComponent('J_FPC5') Or InNet('3V0_ANA') Or InNet('GND') Or InNet('NetJ_FPC5_8') Or InNet('Va_5') Or InNet('Vb_5') Or InNet('Vc_5'))) Detected.

Error : Pad J_FPC5-P2_3 Appears to be unroutable. Violation against Rule - CLR_BK13_ESCAPE_J_FPC5 Clearance Constraint (Gap=0.13mm) (InRegionAbsolute(2755.9055,409.4488,3035.4331,594.4882) And (InComponent('J_FPC5') Or InNet('3V0_ANA') Or InNet('GND') Or InNet('NetJ_FPC5_8') Or InNet('Va_5') Or InNet('Vb_5') Or InNet('Vc_5'))),(InRegionAbsolute(2755.9055,409.4488,3035.4331,594.4882) And (InComponent('J_FPC5') Or InNet('3V0_ANA') Or InNet('GND') Or InNet('NetJ_FPC5_8') Or InNet('Va_5') Or InNet('Vb_5') Or InNet('Vc_5'))) Detected.

Error : Pad J_FPC5-P1_3 Appears to be unroutable. Violation against Rule - CLR_BK13_ESCAPE_J_FPC5 Clearance Constraint (Gap=0.13mm) (InRegionAbsolute(2755.9055,409.4488,3035.4331,594.4882) And (InComponent('J_FPC5') Or InNet('3V0_ANA') Or InNet('GND') Or InNet('NetJ_FPC5_8') Or InNet('Va_5') Or InNet('Vb_5') Or InNet('Vc_5'))),(InRegionAbsolute(2755.9055,409.4488,3035.4331,594.4882) And (InComponent('J_FPC5') Or InNet('3V0_ANA') Or InNet('GND') Or InNet('NetJ_FPC5_8') Or InNet('Va_5') Or InNet('Vb_5') Or InNet('Vc_5'))) Detected.

Error : Pad J_FPC5-10 Appears to be unroutable. Violation against Rule - CLR_BK13_ESCAPE_J_FPC5 Clearance Constraint (Gap=0.13mm) (InRegionAbsolute(2755.9055,409.4488,3035.4331,594.4882) And (InComponent('J_FPC5') Or InNet('3V0_ANA') Or InNet('GND') Or InNet('NetJ_FPC5_8') Or InNet('Va_5') Or InNet('Vb_5') Or InNet('Vc_5'))),(InRegionAbsolute(2755.9055,409.4488,3035.4331,594.4882) And (InComponent('J_FPC5') Or InNet('3V0_ANA') Or InNet('GND') Or InNet('NetJ_FPC5_8') Or InNet('Va_5') Or InNet('Vb_5') Or InNet('Vc_5'))) Detected.

Error : Pad J_FPC4-3 Appears to be unroutable. Violation against Rule - CLR_BK13_ESCAPE_J_FPC4 Clearance Constraint (Gap=0.13mm) (InRegionAbsolute(2244.0945,409.4488,2523.6220,594.4882) And (InComponent('J_FPC4') Or InNet('3V0_ANA') Or InNet('GND') Or InNet('NetJ_FPC4_8') Or InNet('Va_4') Or InNet('Vb_4') Or InNet('Vc_4'))),(InRegionAbsolute(2244.0945,409.4488,2523.6220,594.4882) And (InComponent('J_FPC4') Or InNet('3V0_ANA') Or InNet('GND') Or InNet('NetJ_FPC4_8') Or InNet('Va_4') Or InNet('Vb_4') Or InNet('Vc_4'))) Detected.

Error : Pad J_FPC4-4 Appears to be unroutable. Violation against Rule - CLR_BK13_ESCAPE_J_FPC4 Clearance Constraint (Gap=0.13mm) (InRegionAbsolute(2244.0945,409.4488,2523.6220,594.4882) And (InComponent('J_FPC4') Or InNet('3V0_ANA') Or InNet('GND') Or InNet('NetJ_FPC4_8') Or InNet('Va_4') Or InNet('Vb_4') Or InNet('Vc_4'))),(InRegionAbsolute(2244.0945,409.4488,2523.6220,594.4882) And (InComponent('J_FPC4') Or InNet('3V0_ANA') Or InNet('GND') Or InNet('NetJ_FPC4_8') Or InNet('Va_4') Or InNet('Vb_4') Or InNet('Vc_4'))) Detected.

Error : Pad J_FPC4-5 Appears to be unroutable. Violation against Rule - CLR_BK13_ESCAPE_J_FPC4 Clearance Constraint (Gap=0.13mm) (InRegionAbsolute(2244.0945,409.4488,2523.6220,594.4882) And (InComponent('J_FPC4') Or InNet('3V0_ANA') Or InNet('GND') Or InNet('NetJ_FPC4_8') Or InNet('Va_4') Or InNet('Vb_4') Or InNet('Vc_4'))),(InRegionAbsolute(2244.0945,409.4488,2523.6220,594.4882) And (InComponent('J_FPC4') Or InNet('3V0_ANA') Or InNet('GND') Or InNet('NetJ_FPC4_8') Or InNet('Va_4') Or InNet('Vb_4') Or InNet('Vc_4'))) Detected.

Error : Pad J_FPC4-2 Appears to be unroutable. Violation against Rule - CLR_BK13_ESCAPE_J_FPC4 Clearance Constraint (Gap=0.13mm) (InRegionAbsolute(2244.0945,409.4488,2523.6220,594.4882) And (InComponent('J_FPC4') Or InNet('3V0_ANA') Or InNet('GND') Or InNet('NetJ_FPC4_8') Or InNet('Va_4') Or InNet('Vb_4') Or InNet('Vc_4'))),(InRegionAbsolute(2244.0945,409.4488,2523.6220,594.4882) And (InComponent('J_FPC4') Or InNet('3V0_ANA') Or InNet('GND') Or InNet('NetJ_FPC4_8') Or InNet('Va_4') Or InNet('Vb_4') Or InNet('Vc_4'))) Detected.

Error : Pad J_FPC4-1 Appears to be unroutable. Violation against Rule - CLR_BK13_ESCAPE_J_FPC4 Clearance Constraint (Gap=0.13mm) (InRegionAbsolute(2244.0945,409.4488,2523.6220,594.4882) And (InComponent('J_FPC4') Or InNet('3V0_ANA') Or InNet('GND') Or InNet('NetJ_FPC4_8') Or InNet('Va_4') Or InNet('Vb_4') Or InNet('Vc_4'))),(InRegionAbsolute(2244.0945,409.4488,2523.6220,594.4882) And (InComponent('J_FPC4') Or InNet('3V0_ANA') Or InNet('GND') Or InNet('NetJ_FPC4_8') Or InNet('Va_4') Or InNet('Vb_4') Or InNet('Vc_4'))) Detected.

Error : Pad J_FPC4-8 Appears to be unroutable. Violation against Rule - CLR_BK13_ESCAPE_J_FPC4 Clearance Constraint (Gap=0.13mm) (InRegionAbsolute(2244.0945,409.4488,2523.6220,594.4882) And (InComponent('J_FPC4') Or InNet('3V0_ANA') Or InNet('GND') Or InNet('NetJ_FPC4_8') Or InNet('Va_4') Or InNet('Vb_4') Or InNet('Vc_4'))),(InRegionAbsolute(2244.0945,409.4488,2523.6220,594.4882) And (InComponent('J_FPC4') Or InNet('3V0_ANA') Or InNet('GND') Or InNet('NetJ_FPC4_8') Or InNet('Va_4') Or InNet('Vb_4') Or InNet('Vc_4'))) Detected.

Error : Pad J_FPC4-9 Appears to be unroutable. Violation against Rule - CLR_BK13_ESCAPE_J_FPC4 Clearance Constraint (Gap=0.13mm) (InRegionAbsolute(2244.0945,409.4488,2523.6220,594.4882) And (InComponent('J_FPC4') Or InNet('3V0_ANA') Or InNet('GND') Or InNet('NetJ_FPC4_8') Or InNet('Va_4') Or InNet('Vb_4') Or InNet('Vc_4'))),(InRegionAbsolute(2244.0945,409.4488,2523.6220,594.4882) And (InComponent('J_FPC4') Or InNet('3V0_ANA') Or InNet('GND') Or InNet('NetJ_FPC4_8') Or InNet('Va_4') Or InNet('Vb_4') Or InNet('Vc_4'))) Detected.

Error : Pad J_FPC4-7 Appears to be unroutable. Violation against Rule - CLR_BK13_ESCAPE_J_FPC4 Clearance Constraint (Gap=0.13mm) (InRegionAbsolute(2244.0945,409.4488,2523.6220,594.4882) And (InComponent('J_FPC4') Or InNet('3V0_ANA') Or InNet('GND') Or InNet('NetJ_FPC4_8') Or InNet('Va_4') Or InNet('Vb_4') Or InNet('Vc_4'))),(InRegionAbsolute(2244.0945,409.4488,2523.6220,594.4882) And (InComponent('J_FPC4') Or InNet('3V0_ANA') Or InNet('GND') Or InNet('NetJ_FPC4_8') Or InNet('Va_4') Or InNet('Vb_4') Or InNet('Vc_4'))) Detected.

Error : Pad J_FPC4-6 Appears to be unroutable. Violation against Rule - CLR_BK13_ESCAPE_J_FPC4 Clearance Constraint (Gap=0.13mm) (InRegionAbsolute(2244.0945,409.4488,2523.6220,594.4882) And (InComponent('J_FPC4') Or InNet('3V0_ANA') Or InNet('GND') Or InNet('NetJ_FPC4_8') Or InNet('Va_4') Or InNet('Vb_4') Or InNet('Vc_4'))),(InRegionAbsolute(2244.0945,409.4488,2523.6220,594.4882) And (InComponent('J_FPC4') Or InNet('3V0_ANA') Or InNet('GND') Or InNet('NetJ_FPC4_8') Or InNet('Va_4') Or InNet('Vb_4') Or InNet('Vc_4'))) Detected.

Error : Pad J_FPC4-P1_2 Appears to be unroutable. Violation against Rule - CLR_BK13_ESCAPE_J_FPC4 Clearance Constraint (Gap=0.13mm) (InRegionAbsolute(2244.0945,409.4488,2523.6220,594.4882) And (InComponent('J_FPC4') Or InNet('3V0_ANA') Or InNet('GND') Or InNet('NetJ_FPC4_8') Or InNet('Va_4') Or InNet('Vb_4') Or InNet('Vc_4'))),(InRegionAbsolute(2244.0945,409.4488,2523.6220,594.4882) And (InComponent('J_FPC4') Or InNet('3V0_ANA') Or InNet('GND') Or InNet('NetJ_FPC4_8') Or InNet('Va_4') Or InNet('Vb_4') Or InNet('Vc_4'))) Detected.

Error : Pad J_FPC4-P1_1 Appears to be unroutable. Violation against Rule - CLR_BK13_ESCAPE_J_FPC4 Clearance Constraint (Gap=0.13mm) (InRegionAbsolute(2244.0945,409.4488,2523.6220,594.4882) And (InComponent('J_FPC4') Or InNet('3V0_ANA') Or InNet('GND') Or InNet('NetJ_FPC4_8') Or InNet('Va_4') Or InNet('Vb_4') Or InNet('Vc_4'))),(InRegionAbsolute(2244.0945,409.4488,2523.6220,594.4882) And (InComponent('J_FPC4') Or InNet('3V0_ANA') Or InNet('GND') Or InNet('NetJ_FPC4_8') Or InNet('Va_4') Or InNet('Vb_4') Or InNet('Vc_4'))) Detected.

Error : Pad J_FPC4-P2_1 Appears to be unroutable. Violation against Rule - CLR_BK13_ESCAPE_J_FPC4 Clearance Constraint (Gap=0.13mm) (InRegionAbsolute(2244.0945,409.4488,2523.6220,594.4882) And (InComponent('J_FPC4') Or InNet('3V0_ANA') Or InNet('GND') Or InNet('NetJ_FPC4_8') Or InNet('Va_4') Or InNet('Vb_4') Or InNet('Vc_4'))),(InRegionAbsolute(2244.0945,409.4488,2523.6220,594.4882) And (InComponent('J_FPC4') Or InNet('3V0_ANA') Or InNet('GND') Or InNet('NetJ_FPC4_8') Or InNet('Va_4') Or InNet('Vb_4') Or InNet('Vc_4'))) Detected.

Error : Pad J_FPC4-P2_2 Appears to be unroutable. Violation against Rule - CLR_BK13_ESCAPE_J_FPC4 Clearance Constraint (Gap=0.13mm) (InRegionAbsolute(2244.0945,409.4488,2523.6220,594.4882) And (InComponent('J_FPC4') Or InNet('3V0_ANA') Or InNet('GND') Or InNet('NetJ_FPC4_8') Or InNet('Va_4') Or InNet('Vb_4') Or InNet('Vc_4'))),(InRegionAbsolute(2244.0945,409.4488,2523.6220,594.4882) And (InComponent('J_FPC4') Or InNet('3V0_ANA') Or InNet('GND') Or InNet('NetJ_FPC4_8') Or InNet('Va_4') Or InNet('Vb_4') Or InNet('Vc_4'))) Detected.

Error : Pad J_FPC4-P2_3 Appears to be unroutable. Violation against Rule - CLR_BK13_ESCAPE_J_FPC4 Clearance Constraint (Gap=0.13mm) (InRegionAbsolute(2244.0945,409.4488,2523.6220,594.4882) And (InComponent('J_FPC4') Or InNet('3V0_ANA') Or InNet('GND') Or InNet('NetJ_FPC4_8') Or InNet('Va_4') Or InNet('Vb_4') Or InNet('Vc_4'))),(InRegionAbsolute(2244.0945,409.4488,2523.6220,594.4882) And (InComponent('J_FPC4') Or InNet('3V0_ANA') Or InNet('GND') Or InNet('NetJ_FPC4_8') Or InNet('Va_4') Or InNet('Vb_4') Or InNet('Vc_4'))) Detected.

Error : Pad J_FPC4-P1_3 Appears to be unroutable. Violation against Rule - CLR_BK13_ESCAPE_J_FPC4 Clearance Constraint (Gap=0.13mm) (InRegionAbsolute(2244.0945,409.4488,2523.6220,594.4882) And (InComponent('J_FPC4') Or InNet('3V0_ANA') Or InNet('GND') Or InNet('NetJ_FPC4_8') Or InNet('Va_4') Or InNet('Vb_4') Or InNet('Vc_4'))),(InRegionAbsolute(2244.0945,409.4488,2523.6220,594.4882) And (InComponent('J_FPC4') Or InNet('3V0_ANA') Or InNet('GND') Or InNet('NetJ_FPC4_8') Or InNet('Va_4') Or InNet('Vb_4') Or InNet('Vc_4'))) Detected.

Error : Pad J_FPC4-10 Appears to be unroutable. Violation against Rule - CLR_BK13_ESCAPE_J_FPC4 Clearance Constraint (Gap=0.13mm) (InRegionAbsolute(2244.0945,409.4488,2523.6220,594.4882) And (InComponent('J_FPC4') Or InNet('3V0_ANA') Or InNet('GND') Or InNet('NetJ_FPC4_8') Or InNet('Va_4') Or InNet('Vb_4') Or InNet('Vc_4'))),(InRegionAbsolute(2244.0945,409.4488,2523.6220,594.4882) And (InComponent('J_FPC4') Or InNet('3V0_ANA') Or InNet('GND') Or InNet('NetJ_FPC4_8') Or InNet('Va_4') Or InNet('Vb_4') Or InNet('Vc_4'))) Detected.

Error : Pad J_FPC3-3 Appears to be unroutable. Violation against Rule - CLR_BK13_ESCAPE_J_FPC3 Clearance Constraint (Gap=0.13mm) (InRegionAbsolute(1732.2835,409.4488,2011.8110,594.4882) And (InComponent('J_FPC3') Or InNet('3V0_ANA') Or InNet('GND') Or InNet('NetJ_FPC3_8') Or InNet('Va_3') Or InNet('Vb_3') Or InNet('Vc_3'))),(InRegionAbsolute(1732.2835,409.4488,2011.8110,594.4882) And (InComponent('J_FPC3') Or InNet('3V0_ANA') Or InNet('GND') Or InNet('NetJ_FPC3_8') Or InNet('Va_3') Or InNet('Vb_3') Or InNet('Vc_3'))) Detected.

Error : Pad J_FPC3-4 Appears to be unroutable. Violation against Rule - CLR_BK13_ESCAPE_J_FPC3 Clearance Constraint (Gap=0.13mm) (InRegionAbsolute(1732.2835,409.4488,2011.8110,594.4882) And (InComponent('J_FPC3') Or InNet('3V0_ANA') Or InNet('GND') Or InNet('NetJ_FPC3_8') Or InNet('Va_3') Or InNet('Vb_3') Or InNet('Vc_3'))),(InRegionAbsolute(1732.2835,409.4488,2011.8110,594.4882) And (InComponent('J_FPC3') Or InNet('3V0_ANA') Or InNet('GND') Or InNet('NetJ_FPC3_8') Or InNet('Va_3') Or InNet('Vb_3') Or InNet('Vc_3'))) Detected.

Error : Pad J_FPC3-5 Appears to be unroutable. Violation against Rule - CLR_BK13_ESCAPE_J_FPC3 Clearance Constraint (Gap=0.13mm) (InRegionAbsolute(1732.2835,409.4488,2011.8110,594.4882) And (InComponent('J_FPC3') Or InNet('3V0_ANA') Or InNet('GND') Or InNet('NetJ_FPC3_8') Or InNet('Va_3') Or InNet('Vb_3') Or InNet('Vc_3'))),(InRegionAbsolute(1732.2835,409.4488,2011.8110,594.4882) And (InComponent('J_FPC3') Or InNet('3V0_ANA') Or InNet('GND') Or InNet('NetJ_FPC3_8') Or InNet('Va_3') Or InNet('Vb_3') Or InNet('Vc_3'))) Detected.

Error : Pad J_FPC3-2 Appears to be unroutable. Violation against Rule - CLR_BK13_ESCAPE_J_FPC3 Clearance Constraint (Gap=0.13mm) (InRegionAbsolute(1732.2835,409.4488,2011.8110,594.4882) And (InComponent('J_FPC3') Or InNet('3V0_ANA') Or InNet('GND') Or InNet('NetJ_FPC3_8') Or InNet('Va_3') Or InNet('Vb_3') Or InNet('Vc_3'))),(InRegionAbsolute(1732.2835,409.4488,2011.8110,594.4882) And (InComponent('J_FPC3') Or InNet('3V0_ANA') Or InNet('GND') Or InNet('NetJ_FPC3_8') Or InNet('Va_3') Or InNet('Vb_3') Or InNet('Vc_3'))) Detected.

Error : Pad J_FPC3-1 Appears to be unroutable. Violation against Rule - CLR_BK13_ESCAPE_J_FPC3 Clearance Constraint (Gap=0.13mm) (InRegionAbsolute(1732.2835,409.4488,2011.8110,594.4882) And (InComponent('J_FPC3') Or InNet('3V0_ANA') Or InNet('GND') Or InNet('NetJ_FPC3_8') Or InNet('Va_3') Or InNet('Vb_3') Or InNet('Vc_3'))),(InRegionAbsolute(1732.2835,409.4488,2011.8110,594.4882) And (InComponent('J_FPC3') Or InNet('3V0_ANA') Or InNet('GND') Or InNet('NetJ_FPC3_8') Or InNet('Va_3') Or InNet('Vb_3') Or InNet('Vc_3'))) Detected.

Error : Pad J_FPC3-8 Appears to be unroutable. Violation against Rule - CLR_BK13_ESCAPE_J_FPC3 Clearance Constraint (Gap=0.13mm) (InRegionAbsolute(1732.2835,409.4488,2011.8110,594.4882) And (InComponent('J_FPC3') Or InNet('3V0_ANA') Or InNet('GND') Or InNet('NetJ_FPC3_8') Or InNet('Va_3') Or InNet('Vb_3') Or InNet('Vc_3'))),(InRegionAbsolute(1732.2835,409.4488,2011.8110,594.4882) And (InComponent('J_FPC3') Or InNet('3V0_ANA') Or InNet('GND') Or InNet('NetJ_FPC3_8') Or InNet('Va_3') Or InNet('Vb_3') Or InNet('Vc_3'))) Detected.

Error : Pad J_FPC3-9 Appears to be unroutable. Violation against Rule - CLR_BK13_ESCAPE_J_FPC3 Clearance Constraint (Gap=0.13mm) (InRegionAbsolute(1732.2835,409.4488,2011.8110,594.4882) And (InComponent('J_FPC3') Or InNet('3V0_ANA') Or InNet('GND') Or InNet('NetJ_FPC3_8') Or InNet('Va_3') Or InNet('Vb_3') Or InNet('Vc_3'))),(InRegionAbsolute(1732.2835,409.4488,2011.8110,594.4882) And (InComponent('J_FPC3') Or InNet('3V0_ANA') Or InNet('GND') Or InNet('NetJ_FPC3_8') Or InNet('Va_3') Or InNet('Vb_3') Or InNet('Vc_3'))) Detected.

Error : Pad J_FPC3-7 Appears to be unroutable. Violation against Rule - CLR_BK13_ESCAPE_J_FPC3 Clearance Constraint (Gap=0.13mm) (InRegionAbsolute(1732.2835,409.4488,2011.8110,594.4882) And (InComponent('J_FPC3') Or InNet('3V0_ANA') Or InNet('GND') Or InNet('NetJ_FPC3_8') Or InNet('Va_3') Or InNet('Vb_3') Or InNet('Vc_3'))),(InRegionAbsolute(1732.2835,409.4488,2011.8110,594.4882) And (InComponent('J_FPC3') Or InNet('3V0_ANA') Or InNet('GND') Or InNet('NetJ_FPC3_8') Or InNet('Va_3') Or InNet('Vb_3') Or InNet('Vc_3'))) Detected.

Error : Pad J_FPC3-6 Appears to be unroutable. Violation against Rule - CLR_BK13_ESCAPE_J_FPC3 Clearance Constraint (Gap=0.13mm) (InRegionAbsolute(1732.2835,409.4488,2011.8110,594.4882) And (InComponent('J_FPC3') Or InNet('3V0_ANA') Or InNet('GND') Or InNet('NetJ_FPC3_8') Or InNet('Va_3') Or InNet('Vb_3') Or InNet('Vc_3'))),(InRegionAbsolute(1732.2835,409.4488,2011.8110,594.4882) And (InComponent('J_FPC3') Or InNet('3V0_ANA') Or InNet('GND') Or InNet('NetJ_FPC3_8') Or InNet('Va_3') Or InNet('Vb_3') Or InNet('Vc_3'))) Detected.

Error : Pad J_FPC3-P1_2 Appears to be unroutable. Violation against Rule - CLR_BK13_ESCAPE_J_FPC3 Clearance Constraint (Gap=0.13mm) (InRegionAbsolute(1732.2835,409.4488,2011.8110,594.4882) And (InComponent('J_FPC3') Or InNet('3V0_ANA') Or InNet('GND') Or InNet('NetJ_FPC3_8') Or InNet('Va_3') Or InNet('Vb_3') Or InNet('Vc_3'))),(InRegionAbsolute(1732.2835,409.4488,2011.8110,594.4882) And (InComponent('J_FPC3') Or InNet('3V0_ANA') Or InNet('GND') Or InNet('NetJ_FPC3_8') Or InNet('Va_3') Or InNet('Vb_3') Or InNet('Vc_3'))) Detected.

Error : Pad J_FPC3-P1_1 Appears to be unroutable. Violation against Rule - CLR_BK13_ESCAPE_J_FPC3 Clearance Constraint (Gap=0.13mm) (InRegionAbsolute(1732.2835,409.4488,2011.8110,594.4882) And (InComponent('J_FPC3') Or InNet('3V0_ANA') Or InNet('GND') Or InNet('NetJ_FPC3_8') Or InNet('Va_3') Or InNet('Vb_3') Or InNet('Vc_3'))),(InRegionAbsolute(1732.2835,409.4488,2011.8110,594.4882) And (InComponent('J_FPC3') Or InNet('3V0_ANA') Or InNet('GND') Or InNet('NetJ_FPC3_8') Or InNet('Va_3') Or InNet('Vb_3') Or InNet('Vc_3'))) Detected.

Error : Pad J_FPC3-P2_1 Appears to be unroutable. Violation against Rule - CLR_BK13_ESCAPE_J_FPC3 Clearance Constraint (Gap=0.13mm) (InRegionAbsolute(1732.2835,409.4488,2011.8110,594.4882) And (InComponent('J_FPC3') Or InNet('3V0_ANA') Or InNet('GND') Or InNet('NetJ_FPC3_8') Or InNet('Va_3') Or InNet('Vb_3') Or InNet('Vc_3'))),(InRegionAbsolute(1732.2835,409.4488,2011.8110,594.4882) And (InComponent('J_FPC3') Or InNet('3V0_ANA') Or InNet('GND') Or InNet('NetJ_FPC3_8') Or InNet('Va_3') Or InNet('Vb_3') Or InNet('Vc_3'))) Detected.

Error : Pad J_FPC3-P2_2 Appears to be unroutable. Violation against Rule - CLR_BK13_ESCAPE_J_FPC3 Clearance Constraint (Gap=0.13mm) (InRegionAbsolute(1732.2835,409.4488,2011.8110,594.4882) And (InComponent('J_FPC3') Or InNet('3V0_ANA') Or InNet('GND') Or InNet('NetJ_FPC3_8') Or InNet('Va_3') Or InNet('Vb_3') Or InNet('Vc_3'))),(InRegionAbsolute(1732.2835,409.4488,2011.8110,594.4882) And (InComponent('J_FPC3') Or InNet('3V0_ANA') Or InNet('GND') Or InNet('NetJ_FPC3_8') Or InNet('Va_3') Or InNet('Vb_3') Or InNet('Vc_3'))) Detected.

Error : Pad J_FPC3-P2_3 Appears to be unroutable. Violation against Rule - CLR_BK13_ESCAPE_J_FPC3 Clearance Constraint (Gap=0.13mm) (InRegionAbsolute(1732.2835,409.4488,2011.8110,594.4882) And (InComponent('J_FPC3') Or InNet('3V0_ANA') Or InNet('GND') Or InNet('NetJ_FPC3_8') Or InNet('Va_3') Or InNet('Vb_3') Or InNet('Vc_3'))),(InRegionAbsolute(1732.2835,409.4488,2011.8110,594.4882) And (InComponent('J_FPC3') Or InNet('3V0_ANA') Or InNet('GND') Or InNet('NetJ_FPC3_8') Or InNet('Va_3') Or InNet('Vb_3') Or InNet('Vc_3'))) Detected.

Error : Pad J_FPC3-P1_3 Appears to be unroutable. Violation against Rule - CLR_BK13_ESCAPE_J_FPC3 Clearance Constraint (Gap=0.13mm) (InRegionAbsolute(1732.2835,409.4488,2011.8110,594.4882) And (InComponent('J_FPC3') Or InNet('3V0_ANA') Or InNet('GND') Or InNet('NetJ_FPC3_8') Or InNet('Va_3') Or InNet('Vb_3') Or InNet('Vc_3'))),(InRegionAbsolute(1732.2835,409.4488,2011.8110,594.4882) And (InComponent('J_FPC3') Or InNet('3V0_ANA') Or InNet('GND') Or InNet('NetJ_FPC3_8') Or InNet('Va_3') Or InNet('Vb_3') Or InNet('Vc_3'))) Detected.

Error : Pad J_FPC3-10 Appears to be unroutable. Violation against Rule - CLR_BK13_ESCAPE_J_FPC3 Clearance Constraint (Gap=0.13mm) (InRegionAbsolute(1732.2835,409.4488,2011.8110,594.4882) And (InComponent('J_FPC3') Or InNet('3V0_ANA') Or InNet('GND') Or InNet('NetJ_FPC3_8') Or InNet('Va_3') Or InNet('Vb_3') Or InNet('Vc_3'))),(InRegionAbsolute(1732.2835,409.4488,2011.8110,594.4882) And (InComponent('J_FPC3') Or InNet('3V0_ANA') Or InNet('GND') Or InNet('NetJ_FPC3_8') Or InNet('Va_3') Or InNet('Vb_3') Or InNet('Vc_3'))) Detected.

Error : Pad J_FPC2-3 Appears to be unroutable. Violation against Rule - CLR_BK13_ESCAPE_J_FPC2 Clearance Constraint (Gap=0.13mm) (InRegionAbsolute(1220.4724,409.4488,1500.0000,594.4882) And (InComponent('J_FPC2') Or InNet('3V0_ANA') Or InNet('GND') Or InNet('NetJ_FPC2_8') Or InNet('Va_2') Or InNet('Vb_2') Or InNet('Vc_2'))),(InRegionAbsolute(1220.4724,409.4488,1500.0000,594.4882) And (InComponent('J_FPC2') Or InNet('3V0_ANA') Or InNet('GND') Or InNet('NetJ_FPC2_8') Or InNet('Va_2') Or InNet('Vb_2') Or InNet('Vc_2'))) Detected.

Error : Pad J_FPC2-4 Appears to be unroutable. Violation against Rule - CLR_BK13_ESCAPE_J_FPC2 Clearance Constraint (Gap=0.13mm) (InRegionAbsolute(1220.4724,409.4488,1500.0000,594.4882) And (InComponent('J_FPC2') Or InNet('3V0_ANA') Or InNet('GND') Or InNet('NetJ_FPC2_8') Or InNet('Va_2') Or InNet('Vb_2') Or InNet('Vc_2'))),(InRegionAbsolute(1220.4724,409.4488,1500.0000,594.4882) And (InComponent('J_FPC2') Or InNet('3V0_ANA') Or InNet('GND') Or InNet('NetJ_FPC2_8') Or InNet('Va_2') Or InNet('Vb_2') Or InNet('Vc_2'))) Detected.

Error : Pad J_FPC2-5 Appears to be unroutable. Violation against Rule - CLR_BK13_ESCAPE_J_FPC2 Clearance Constraint (Gap=0.13mm) (InRegionAbsolute(1220.4724,409.4488,1500.0000,594.4882) And (InComponent('J_FPC2') Or InNet('3V0_ANA') Or InNet('GND') Or InNet('NetJ_FPC2_8') Or InNet('Va_2') Or InNet('Vb_2') Or InNet('Vc_2'))),(InRegionAbsolute(1220.4724,409.4488,1500.0000,594.4882) And (InComponent('J_FPC2') Or InNet('3V0_ANA') Or InNet('GND') Or InNet('NetJ_FPC2_8') Or InNet('Va_2') Or InNet('Vb_2') Or InNet('Vc_2'))) Detected.

Error : Pad J_FPC2-2 Appears to be unroutable. Violation against Rule - CLR_BK13_ESCAPE_J_FPC2 Clearance Constraint (Gap=0.13mm) (InRegionAbsolute(1220.4724,409.4488,1500.0000,594.4882) And (InComponent('J_FPC2') Or InNet('3V0_ANA') Or InNet('GND') Or InNet('NetJ_FPC2_8') Or InNet('Va_2') Or InNet('Vb_2') Or InNet('Vc_2'))),(InRegionAbsolute(1220.4724,409.4488,1500.0000,594.4882) And (InComponent('J_FPC2') Or InNet('3V0_ANA') Or InNet('GND') Or InNet('NetJ_FPC2_8') Or InNet('Va_2') Or InNet('Vb_2') Or InNet('Vc_2'))) Detected.

Error : Pad J_FPC2-1 Appears to be unroutable. Violation against Rule - CLR_BK13_ESCAPE_J_FPC2 Clearance Constraint (Gap=0.13mm) (InRegionAbsolute(1220.4724,409.4488,1500.0000,594.4882) And (InComponent('J_FPC2') Or InNet('3V0_ANA') Or InNet('GND') Or InNet('NetJ_FPC2_8') Or InNet('Va_2') Or InNet('Vb_2') Or InNet('Vc_2'))),(InRegionAbsolute(1220.4724,409.4488,1500.0000,594.4882) And (InComponent('J_FPC2') Or InNet('3V0_ANA') Or InNet('GND') Or InNet('NetJ_FPC2_8') Or InNet('Va_2') Or InNet('Vb_2') Or InNet('Vc_2'))) Detected.

Error : Pad J_FPC2-8 Appears to be unroutable. Violation against Rule - CLR_BK13_ESCAPE_J_FPC2 Clearance Constraint (Gap=0.13mm) (InRegionAbsolute(1220.4724,409.4488,1500.0000,594.4882) And (InComponent('J_FPC2') Or InNet('3V0_ANA') Or InNet('GND') Or InNet('NetJ_FPC2_8') Or InNet('Va_2') Or InNet('Vb_2') Or InNet('Vc_2'))),(InRegionAbsolute(1220.4724,409.4488,1500.0000,594.4882) And (InComponent('J_FPC2') Or InNet('3V0_ANA') Or InNet('GND') Or InNet('NetJ_FPC2_8') Or InNet('Va_2') Or InNet('Vb_2') Or InNet('Vc_2'))) Detected.

Error : Pad J_FPC2-9 Appears to be unroutable. Violation against Rule - CLR_BK13_ESCAPE_J_FPC2 Clearance Constraint (Gap=0.13mm) (InRegionAbsolute(1220.4724,409.4488,1500.0000,594.4882) And (InComponent('J_FPC2') Or InNet('3V0_ANA') Or InNet('GND') Or InNet('NetJ_FPC2_8') Or InNet('Va_2') Or InNet('Vb_2') Or InNet('Vc_2'))),(InRegionAbsolute(1220.4724,409.4488,1500.0000,594.4882) And (InComponent('J_FPC2') Or InNet('3V0_ANA') Or InNet('GND') Or InNet('NetJ_FPC2_8') Or InNet('Va_2') Or InNet('Vb_2') Or InNet('Vc_2'))) Detected.

Error : Pad J_FPC2-7 Appears to be unroutable. Violation against Rule - CLR_BK13_ESCAPE_J_FPC2 Clearance Constraint (Gap=0.13mm) (InRegionAbsolute(1220.4724,409.4488,1500.0000,594.4882) And (InComponent('J_FPC2') Or InNet('3V0_ANA') Or InNet('GND') Or InNet('NetJ_FPC2_8') Or InNet('Va_2') Or InNet('Vb_2') Or InNet('Vc_2'))),(InRegionAbsolute(1220.4724,409.4488,1500.0000,594.4882) And (InComponent('J_FPC2') Or InNet('3V0_ANA') Or InNet('GND') Or InNet('NetJ_FPC2_8') Or InNet('Va_2') Or InNet('Vb_2') Or InNet('Vc_2'))) Detected.

Error : Pad J_FPC2-6 Appears to be unroutable. Violation against Rule - CLR_BK13_ESCAPE_J_FPC2 Clearance Constraint (Gap=0.13mm) (InRegionAbsolute(1220.4724,409.4488,1500.0000,594.4882) And (InComponent('J_FPC2') Or InNet('3V0_ANA') Or InNet('GND') Or InNet('NetJ_FPC2_8') Or InNet('Va_2') Or InNet('Vb_2') Or InNet('Vc_2'))),(InRegionAbsolute(1220.4724,409.4488,1500.0000,594.4882) And (InComponent('J_FPC2') Or InNet('3V0_ANA') Or InNet('GND') Or InNet('NetJ_FPC2_8') Or InNet('Va_2') Or InNet('Vb_2') Or InNet('Vc_2'))) Detected.

Error : Pad J_FPC2-P1_2 Appears to be unroutable. Violation against Rule - CLR_BK13_ESCAPE_J_FPC2 Clearance Constraint (Gap=0.13mm) (InRegionAbsolute(1220.4724,409.4488,1500.0000,594.4882) And (InComponent('J_FPC2') Or InNet('3V0_ANA') Or InNet('GND') Or InNet('NetJ_FPC2_8') Or InNet('Va_2') Or InNet('Vb_2') Or InNet('Vc_2'))),(InRegionAbsolute(1220.4724,409.4488,1500.0000,594.4882) And (InComponent('J_FPC2') Or InNet('3V0_ANA') Or InNet('GND') Or InNet('NetJ_FPC2_8') Or InNet('Va_2') Or InNet('Vb_2') Or InNet('Vc_2'))) Detected.

Error : Pad J_FPC2-P1_1 Appears to be unroutable. Violation against Rule - CLR_BK13_ESCAPE_J_FPC2 Clearance Constraint (Gap=0.13mm) (InRegionAbsolute(1220.4724,409.4488,1500.0000,594.4882) And (InComponent('J_FPC2') Or InNet('3V0_ANA') Or InNet('GND') Or InNet('NetJ_FPC2_8') Or InNet('Va_2') Or InNet('Vb_2') Or InNet('Vc_2'))),(InRegionAbsolute(1220.4724,409.4488,1500.0000,594.4882) And (InComponent('J_FPC2') Or InNet('3V0_ANA') Or InNet('GND') Or InNet('NetJ_FPC2_8') Or InNet('Va_2') Or InNet('Vb_2') Or InNet('Vc_2'))) Detected.

Error : Pad J_FPC2-P2_1 Appears to be unroutable. Violation against Rule - CLR_BK13_ESCAPE_J_FPC2 Clearance Constraint (Gap=0.13mm) (InRegionAbsolute(1220.4724,409.4488,1500.0000,594.4882) And (InComponent('J_FPC2') Or InNet('3V0_ANA') Or InNet('GND') Or InNet('NetJ_FPC2_8') Or InNet('Va_2') Or InNet('Vb_2') Or InNet('Vc_2'))),(InRegionAbsolute(1220.4724,409.4488,1500.0000,594.4882) And (InComponent('J_FPC2') Or InNet('3V0_ANA') Or InNet('GND') Or InNet('NetJ_FPC2_8') Or InNet('Va_2') Or InNet('Vb_2') Or InNet('Vc_2'))) Detected.

Error : Pad J_FPC2-P2_2 Appears to be unroutable. Violation against Rule - CLR_BK13_ESCAPE_J_FPC2 Clearance Constraint (Gap=0.13mm) (InRegionAbsolute(1220.4724,409.4488,1500.0000,594.4882) And (InComponent('J_FPC2') Or InNet('3V0_ANA') Or InNet('GND') Or InNet('NetJ_FPC2_8') Or InNet('Va_2') Or InNet('Vb_2') Or InNet('Vc_2'))),(InRegionAbsolute(1220.4724,409.4488,1500.0000,594.4882) And (InComponent('J_FPC2') Or InNet('3V0_ANA') Or InNet('GND') Or InNet('NetJ_FPC2_8') Or InNet('Va_2') Or InNet('Vb_2') Or InNet('Vc_2'))) Detected.

Error : Pad J_FPC2-P2_3 Appears to be unroutable. Violation against Rule - CLR_BK13_ESCAPE_J_FPC2 Clearance Constraint (Gap=0.13mm) (InRegionAbsolute(1220.4724,409.4488,1500.0000,594.4882) And (InComponent('J_FPC2') Or InNet('3V0_ANA') Or InNet('GND') Or InNet('NetJ_FPC2_8') Or InNet('Va_2') Or InNet('Vb_2') Or InNet('Vc_2'))),(InRegionAbsolute(1220.4724,409.4488,1500.0000,594.4882) And (InComponent('J_FPC2') Or InNet('3V0_ANA') Or InNet('GND') Or InNet('NetJ_FPC2_8') Or InNet('Va_2') Or InNet('Vb_2') Or InNet('Vc_2'))) Detected.

Error : Pad J_FPC2-P1_3 Appears to be unroutable. Violation against Rule - CLR_BK13_ESCAPE_J_FPC2 Clearance Constraint (Gap=0.13mm) (InRegionAbsolute(1220.4724,409.4488,1500.0000,594.4882) And (InComponent('J_FPC2') Or InNet('3V0_ANA') Or InNet('GND') Or InNet('NetJ_FPC2_8') Or InNet('Va_2') Or InNet('Vb_2') Or InNet('Vc_2'))),(InRegionAbsolute(1220.4724,409.4488,1500.0000,594.4882) And (InComponent('J_FPC2') Or InNet('3V0_ANA') Or InNet('GND') Or InNet('NetJ_FPC2_8') Or InNet('Va_2') Or InNet('Vb_2') Or InNet('Vc_2'))) Detected.

Error : Pad J_FPC2-10 Appears to be unroutable. Violation against Rule - CLR_BK13_ESCAPE_J_FPC2 Clearance Constraint (Gap=0.13mm) (InRegionAbsolute(1220.4724,409.4488,1500.0000,594.4882) And (InComponent('J_FPC2') Or InNet('3V0_ANA') Or InNet('GND') Or InNet('NetJ_FPC2_8') Or InNet('Va_2') Or InNet('Vb_2') Or InNet('Vc_2'))),(InRegionAbsolute(1220.4724,409.4488,1500.0000,594.4882) And (InComponent('J_FPC2') Or InNet('3V0_ANA') Or InNet('GND') Or InNet('NetJ_FPC2_8') Or InNet('Va_2') Or InNet('Vb_2') Or InNet('Vc_2'))) Detected.

Error : Pad J_FPC1-3 Appears to be unroutable. Violation against Rule - CLR_BK13_ESCAPE_J_FPC1 Clearance Constraint (Gap=0.13mm) (InRegionAbsolute(708.6614,409.4488,988.1890,594.4882) And (InComponent('J_FPC1') Or InNet('3V0_ANA') Or InNet('GND') Or InNet('NetJ_FPC1_8') Or InNet('Va_1') Or InNet('Vb_1') Or InNet('Vc_1'))),(InRegionAbsolute(708.6614,409.4488,988.1890,594.4882) And (InComponent('J_FPC1') Or InNet('3V0_ANA') Or InNet('GND') Or InNet('NetJ_FPC1_8') Or InNet('Va_1') Or InNet('Vb_1') Or InNet('Vc_1'))) Detected.

Error : Pad J_FPC1-4 Appears to be unroutable. Violation against Rule - CLR_BK13_ESCAPE_J_FPC1 Clearance Constraint (Gap=0.13mm) (InRegionAbsolute(708.6614,409.4488,988.1890,594.4882) And (InComponent('J_FPC1') Or InNet('3V0_ANA') Or InNet('GND') Or InNet('NetJ_FPC1_8') Or InNet('Va_1') Or InNet('Vb_1') Or InNet('Vc_1'))),(InRegionAbsolute(708.6614,409.4488,988.1890,594.4882) And (InComponent('J_FPC1') Or InNet('3V0_ANA') Or InNet('GND') Or InNet('NetJ_FPC1_8') Or InNet('Va_1') Or InNet('Vb_1') Or InNet('Vc_1'))) Detected.

Error : Pad J_FPC1-5 Appears to be unroutable. Violation against Rule - CLR_BK13_ESCAPE_J_FPC1 Clearance Constraint (Gap=0.13mm) (InRegionAbsolute(708.6614,409.4488,988.1890,594.4882) And (InComponent('J_FPC1') Or InNet('3V0_ANA') Or InNet('GND') Or InNet('NetJ_FPC1_8') Or InNet('Va_1') Or InNet('Vb_1') Or InNet('Vc_1'))),(InRegionAbsolute(708.6614,409.4488,988.1890,594.4882) And (InComponent('J_FPC1') Or InNet('3V0_ANA') Or InNet('GND') Or InNet('NetJ_FPC1_8') Or InNet('Va_1') Or InNet('Vb_1') Or InNet('Vc_1'))) Detected.

Error : Pad J_FPC1-2 Appears to be unroutable. Violation against Rule - CLR_BK13_ESCAPE_J_FPC1 Clearance Constraint (Gap=0.13mm) (InRegionAbsolute(708.6614,409.4488,988.1890,594.4882) And (InComponent('J_FPC1') Or InNet('3V0_ANA') Or InNet('GND') Or InNet('NetJ_FPC1_8') Or InNet('Va_1') Or InNet('Vb_1') Or InNet('Vc_1'))),(InRegionAbsolute(708.6614,409.4488,988.1890,594.4882) And (InComponent('J_FPC1') Or InNet('3V0_ANA') Or InNet('GND') Or InNet('NetJ_FPC1_8') Or InNet('Va_1') Or InNet('Vb_1') Or InNet('Vc_1'))) Detected.

Error : Pad J_FPC1-1 Appears to be unroutable. Violation against Rule - CLR_BK13_ESCAPE_J_FPC1 Clearance Constraint (Gap=0.13mm) (InRegionAbsolute(708.6614,409.4488,988.1890,594.4882) And (InComponent('J_FPC1') Or InNet('3V0_ANA') Or InNet('GND') Or InNet('NetJ_FPC1_8') Or InNet('Va_1') Or InNet('Vb_1') Or InNet('Vc_1'))),(InRegionAbsolute(708.6614,409.4488,988.1890,594.4882) And (InComponent('J_FPC1') Or InNet('3V0_ANA') Or InNet('GND') Or InNet('NetJ_FPC1_8') Or InNet('Va_1') Or InNet('Vb_1') Or InNet('Vc_1'))) Detected.

Error : Pad J_FPC1-8 Appears to be unroutable. Violation against Rule - CLR_BK13_ESCAPE_J_FPC1 Clearance Constraint (Gap=0.13mm) (InRegionAbsolute(708.6614,409.4488,988.1890,594.4882) And (InComponent('J_FPC1') Or InNet('3V0_ANA') Or InNet('GND') Or InNet('NetJ_FPC1_8') Or InNet('Va_1') Or InNet('Vb_1') Or InNet('Vc_1'))),(InRegionAbsolute(708.6614,409.4488,988.1890,594.4882) And (InComponent('J_FPC1') Or InNet('3V0_ANA') Or InNet('GND') Or InNet('NetJ_FPC1_8') Or InNet('Va_1') Or InNet('Vb_1') Or InNet('Vc_1'))) Detected.

Error : Pad J_FPC1-9 Appears to be unroutable. Violation against Rule - CLR_BK13_ESCAPE_J_FPC1 Clearance Constraint (Gap=0.13mm) (InRegionAbsolute(708.6614,409.4488,988.1890,594.4882) And (InComponent('J_FPC1') Or InNet('3V0_ANA') Or InNet('GND') Or InNet('NetJ_FPC1_8') Or InNet('Va_1') Or InNet('Vb_1') Or InNet('Vc_1'))),(InRegionAbsolute(708.6614,409.4488,988.1890,594.4882) And (InComponent('J_FPC1') Or InNet('3V0_ANA') Or InNet('GND') Or InNet('NetJ_FPC1_8') Or InNet('Va_1') Or InNet('Vb_1') Or InNet('Vc_1'))) Detected.

Error : Pad J_FPC1-7 Appears to be unroutable. Violation against Rule - CLR_BK13_ESCAPE_J_FPC1 Clearance Constraint (Gap=0.13mm) (InRegionAbsolute(708.6614,409.4488,988.1890,594.4882) And (InComponent('J_FPC1') Or InNet('3V0_ANA') Or InNet('GND') Or InNet('NetJ_FPC1_8') Or InNet('Va_1') Or InNet('Vb_1') Or InNet('Vc_1'))),(InRegionAbsolute(708.6614,409.4488,988.1890,594.4882) And (InComponent('J_FPC1') Or InNet('3V0_ANA') Or InNet('GND') Or InNet('NetJ_FPC1_8') Or InNet('Va_1') Or InNet('Vb_1') Or InNet('Vc_1'))) Detected.

Error : Pad J_FPC1-6 Appears to be unroutable. Violation against Rule - CLR_BK13_ESCAPE_J_FPC1 Clearance Constraint (Gap=0.13mm) (InRegionAbsolute(708.6614,409.4488,988.1890,594.4882) And (InComponent('J_FPC1') Or InNet('3V0_ANA') Or InNet('GND') Or InNet('NetJ_FPC1_8') Or InNet('Va_1') Or InNet('Vb_1') Or InNet('Vc_1'))),(InRegionAbsolute(708.6614,409.4488,988.1890,594.4882) And (InComponent('J_FPC1') Or InNet('3V0_ANA') Or InNet('GND') Or InNet('NetJ_FPC1_8') Or InNet('Va_1') Or InNet('Vb_1') Or InNet('Vc_1'))) Detected.

Error : Pad J_FPC1-P1_2 Appears to be unroutable. Violation against Rule - CLR_BK13_ESCAPE_J_FPC1 Clearance Constraint (Gap=0.13mm) (InRegionAbsolute(708.6614,409.4488,988.1890,594.4882) And (InComponent('J_FPC1') Or InNet('3V0_ANA') Or InNet('GND') Or InNet('NetJ_FPC1_8') Or InNet('Va_1') Or InNet('Vb_1') Or InNet('Vc_1'))),(InRegionAbsolute(708.6614,409.4488,988.1890,594.4882) And (InComponent('J_FPC1') Or InNet('3V0_ANA') Or InNet('GND') Or InNet('NetJ_FPC1_8') Or InNet('Va_1') Or InNet('Vb_1') Or InNet('Vc_1'))) Detected.

Error : Pad J_FPC1-P1_1 Appears to be unroutable. Violation against Rule - CLR_BK13_ESCAPE_J_FPC1 Clearance Constraint (Gap=0.13mm) (InRegionAbsolute(708.6614,409.4488,988.1890,594.4882) And (InComponent('J_FPC1') Or InNet('3V0_ANA') Or InNet('GND') Or InNet('NetJ_FPC1_8') Or InNet('Va_1') Or InNet('Vb_1') Or InNet('Vc_1'))),(InRegionAbsolute(708.6614,409.4488,988.1890,594.4882) And (InComponent('J_FPC1') Or InNet('3V0_ANA') Or InNet('GND') Or InNet('NetJ_FPC1_8') Or InNet('Va_1') Or InNet('Vb_1') Or InNet('Vc_1'))) Detected.

Error : Pad J_FPC1-P2_1 Appears to be unroutable. Violation against Rule - CLR_BK13_ESCAPE_J_FPC1 Clearance Constraint (Gap=0.13mm) (InRegionAbsolute(708.6614,409.4488,988.1890,594.4882) And (InComponent('J_FPC1') Or InNet('3V0_ANA') Or InNet('GND') Or InNet('NetJ_FPC1_8') Or InNet('Va_1') Or InNet('Vb_1') Or InNet('Vc_1'))),(InRegionAbsolute(708.6614,409.4488,988.1890,594.4882) And (InComponent('J_FPC1') Or InNet('3V0_ANA') Or InNet('GND') Or InNet('NetJ_FPC1_8') Or InNet('Va_1') Or InNet('Vb_1') Or InNet('Vc_1'))) Detected.

Error : Pad J_FPC1-P2_2 Appears to be unroutable. Violation against Rule - CLR_BK13_ESCAPE_J_FPC1 Clearance Constraint (Gap=0.13mm) (InRegionAbsolute(708.6614,409.4488,988.1890,594.4882) And (InComponent('J_FPC1') Or InNet('3V0_ANA') Or InNet('GND') Or InNet('NetJ_FPC1_8') Or InNet('Va_1') Or InNet('Vb_1') Or InNet('Vc_1'))),(InRegionAbsolute(708.6614,409.4488,988.1890,594.4882) And (InComponent('J_FPC1') Or InNet('3V0_ANA') Or InNet('GND') Or InNet('NetJ_FPC1_8') Or InNet('Va_1') Or InNet('Vb_1') Or InNet('Vc_1'))) Detected.

Error : Pad J_FPC1-P2_3 Appears to be unroutable. Violation against Rule - CLR_BK13_ESCAPE_J_FPC1 Clearance Constraint (Gap=0.13mm) (InRegionAbsolute(708.6614,409.4488,988.1890,594.4882) And (InComponent('J_FPC1') Or InNet('3V0_ANA') Or InNet('GND') Or InNet('NetJ_FPC1_8') Or InNet('Va_1') Or InNet('Vb_1') Or InNet('Vc_1'))),(InRegionAbsolute(708.6614,409.4488,988.1890,594.4882) And (InComponent('J_FPC1') Or InNet('3V0_ANA') Or InNet('GND') Or InNet('NetJ_FPC1_8') Or InNet('Va_1') Or InNet('Vb_1') Or InNet('Vc_1'))) Detected.

Error : Pad J_FPC1-P1_3 Appears to be unroutable. Violation against Rule - CLR_BK13_ESCAPE_J_FPC1 Clearance Constraint (Gap=0.13mm) (InRegionAbsolute(708.6614,409.4488,988.1890,594.4882) And (InComponent('J_FPC1') Or InNet('3V0_ANA') Or InNet('GND') Or InNet('NetJ_FPC1_8') Or InNet('Va_1') Or InNet('Vb_1') Or InNet('Vc_1'))),(InRegionAbsolute(708.6614,409.4488,988.1890,594.4882) And (InComponent('J_FPC1') Or InNet('3V0_ANA') Or InNet('GND') Or InNet('NetJ_FPC1_8') Or InNet('Va_1') Or InNet('Vb_1') Or InNet('Vc_1'))) Detected.

Error : Pad J_FPC1-10 Appears to be unroutable. Violation against Rule - CLR_BK13_ESCAPE_J_FPC1 Clearance Constraint (Gap=0.13mm) (InRegionAbsolute(708.6614,409.4488,988.1890,594.4882) And (InComponent('J_FPC1') Or InNet('3V0_ANA') Or InNet('GND') Or InNet('NetJ_FPC1_8') Or InNet('Va_1') Or InNet('Vb_1') Or InNet('Vc_1'))),(InRegionAbsolute(708.6614,409.4488,988.1890,594.4882) And (InComponent('J_FPC1') Or InNet('3V0_ANA') Or InNet('GND') Or InNet('NetJ_FPC1_8') Or InNet('Va_1') Or InNet('Vb_1') Or InNet('Vc_1'))) Detected.

Warning : Rule - WIDTH_EMG_GND Width Constraint (Min=0.15mm) (Max=3mm) (Preferred=0.25mm) (InNetClass('EMG_GND'))
Preferred routing width is greater than some pad dimensions. Consider adding a new SMD Neckdown Rule.

Warning : Rule - WIDTH_EMG_ANALOG Width Constraint (Min=0.15mm) (Max=0.4mm) (Preferred=0.2mm) (InNetClass('EMG_ANALOG'))
Preferred routing width is greater than some pad dimensions. Consider adding a new SMD Neckdown Rule.

Warning : Rule - WIDTH_EMG_REFERENCE Width Constraint (Min=0.15mm) (Max=0.5mm) (Preferred=0.2mm) (InNetClass('EMG_REFERENCE'))
Preferred routing width is greater than some pad dimensions. Consider adding a new SMD Neckdown Rule.

Warning : Rule - WIDTH_EMG_POWER Width Constraint (Min=0.15mm) (Max=3mm) (Preferred=0.25mm) (InNetClass('EMG_POWER'))
Preferred routing width is greater than some pad dimensions. Consider adding a new SMD Neckdown Rule.

Hint: no default SMDNeckDown rule exists.

Report Contents

Routing Widths

Routing Via Styles

Electrical Clearances

Fanout Styles

Layer Directions

Drill Pairs

Net Topologies

Net Layers

SMD Neckdown Rules

Unroutable pads

SMD Neckdown Width Warnings

SMD Entry Warnings

Routing Widths | Affected Nets
Rule - Width Width Constraint (Min=0.15mm) (Max=0.5mm) (Preferred=0.2mm) (All) | 4
Rule - WIDTH_EMG_CRYSTAL Width Constraint (Min=0.15mm) (Max=0.3mm) (Preferred=0.2mm) (InNetClass('EMG_CRYSTAL')) | 4
Rule - WIDTH_EMG_CONTROL Width Constraint (Min=0.15mm) (Max=0.5mm) (Preferred=0.2mm) (InNetClass('EMG_CONTROL')) | 38
Rule - WIDTH_EMG_SPI Width Constraint (Min=0.15mm) (Max=0.3mm) (Preferred=0.18mm) (InNetClass('EMG_SPI')) | 8
Rule - WIDTH_EMG_POWER Width Constraint (Min=0.15mm) (Max=3mm) (Preferred=0.25mm) (InNetClass('EMG_POWER')) | 5
Rule - WIDTH_EMG_ANALOG Width Constraint (Min=0.15mm) (Max=0.4mm) (Preferred=0.2mm) (InNetClass('EMG_ANALOG')) | 56
Rule - WIDTH_EMG_REFERENCE Width Constraint (Min=0.15mm) (Max=0.5mm) (Preferred=0.2mm) (InNetClass('EMG_REFERENCE')) | 8
Rule - WIDTH_EMG_ADC Width Constraint (Min=0.15mm) (Max=0.3mm) (Preferred=0.2mm) (InNetClass('EMG_ADC')) | 10
Rule - WIDTH_EMG_SWITCH Width Constraint (Min=0.2mm) (Max=1.5mm) (Preferred=0.3mm) (InNetClass('EMG_SWITCH')) | 2
Rule - WIDTH_EMG_GND Width Constraint (Min=0.15mm) (Max=3mm) (Preferred=0.25mm) (InNetClass('EMG_GND')) | 1

Back to top

Routing Via Styles | Affected Nets
Rule - VIA_STD_060_030 Routing Via (MinHoleWidth=0.3mm) (MaxHoleWidth=0.3mm) (PreferredHoleWidth=0.3mm) (MinWidth=0.6mm) (MaxWidth=0.6mm) (PreferedWidth=0.6mm) (All) | 136

Back to top

Clearance Rules

Rule - CLR_BK13_ESCAPE_J_FPC5 Clearance Constraint (Gap=0.13mm) (InRegionAbsolute(2755.9055,409.4488,3035.4331,594.4882) And (InComponent('J_FPC5') Or InNet('3V0_ANA') Or InNet('GND') Or InNet('NetJ_FPC5_8') Or InNet('Va_5') Or InNet('Vb_5') Or InNet('Vc_5'))),(InRegionAbsolute(2755.9055,409.4488,3035.4331,594.4882) And (InComponent('J_FPC5') Or InNet('3V0_ANA') Or InNet('GND') Or InNet('NetJ_FPC5_8') Or InNet('Va_5') Or InNet('Vb_5') Or InNet('Vc_5')))

Rule - CLR_BK13_ESCAPE_J_FPC4 Clearance Constraint (Gap=0.13mm) (InRegionAbsolute(2244.0945,409.4488,2523.6220,594.4882) And (InComponent('J_FPC4') Or InNet('3V0_ANA') Or InNet('GND') Or InNet('NetJ_FPC4_8') Or InNet('Va_4') Or InNet('Vb_4') Or InNet('Vc_4'))),(InRegionAbsolute(2244.0945,409.4488,2523.6220,594.4882) And (InComponent('J_FPC4') Or InNet('3V0_ANA') Or InNet('GND') Or InNet('NetJ_FPC4_8') Or InNet('Va_4') Or InNet('Vb_4') Or InNet('Vc_4')))

Rule - CLR_BK13_ESCAPE_J_FPC3 Clearance Constraint (Gap=0.13mm) (InRegionAbsolute(1732.2835,409.4488,2011.8110,594.4882) And (InComponent('J_FPC3') Or InNet('3V0_ANA') Or InNet('GND') Or InNet('NetJ_FPC3_8') Or InNet('Va_3') Or InNet('Vb_3') Or InNet('Vc_3'))),(InRegionAbsolute(1732.2835,409.4488,2011.8110,594.4882) And (InComponent('J_FPC3') Or InNet('3V0_ANA') Or InNet('GND') Or InNet('NetJ_FPC3_8') Or InNet('Va_3') Or InNet('Vb_3') Or InNet('Vc_3')))

Rule - CLR_BK13_ESCAPE_J_FPC2 Clearance Constraint (Gap=0.13mm) (InRegionAbsolute(1220.4724,409.4488,1500.0000,594.4882) And (InComponent('J_FPC2') Or InNet('3V0_ANA') Or InNet('GND') Or InNet('NetJ_FPC2_8') Or InNet('Va_2') Or InNet('Vb_2') Or InNet('Vc_2'))),(InRegionAbsolute(1220.4724,409.4488,1500.0000,594.4882) And (InComponent('J_FPC2') Or InNet('3V0_ANA') Or InNet('GND') Or InNet('NetJ_FPC2_8') Or InNet('Va_2') Or InNet('Vb_2') Or InNet('Vc_2')))

Rule - CLR_BK13_ESCAPE_J_FPC1 Clearance Constraint (Gap=0.13mm) (InRegionAbsolute(708.6614,409.4488,988.1890,594.4882) And (InComponent('J_FPC1') Or InNet('3V0_ANA') Or InNet('GND') Or InNet('NetJ_FPC1_8') Or InNet('Va_1') Or InNet('Vb_1') Or InNet('Vc_1'))),(InRegionAbsolute(708.6614,409.4488,988.1890,594.4882) And (InComponent('J_FPC1') Or InNet('3V0_ANA') Or InNet('GND') Or InNet('NetJ_FPC1_8') Or InNet('Va_1') Or InNet('Vb_1') Or InNet('Vc_1')))

Rule - CLR_FINE_ESCAPE_C_DRL_DEC Clearance Constraint (Gap=0.15mm) (IsPad And InComponent('C_DRL_DEC')),(IsTrack And InRegionAbsolute(698.8189,1125.9843,797.2441,1251.9685))

Rule - CLR_FINE_ESCAPE_U_DRL1 Clearance Constraint (Gap=0.15mm) (IsPad And InComponent('U_DRL1')),(IsTrack And InRegionAbsolute(750.0000,1131.8898,982.2835,1309.0551))

Rule - CLR_FINE_ESCAPE_UP4 Clearance Constraint (Gap=0.15mm) (IsPad And InComponent('UP4')),(IsTrack And InRegionAbsolute(796.6535,1402.1654,982.8740,1550.5906))

Rule - CLR_FINE_ESCAPE_UP2 Clearance Constraint (Gap=0.15mm) (IsPad And InComponent('UP2')),(IsTrack And InRegionAbsolute(1263.3858,1690.3543,1413.7795,1852.9528))

Rule - CLR_FINE_ESCAPE_UP1 Clearance Constraint (Gap=0.15mm) (IsPad And InComponent('UP1')),(IsTrack And InRegionAbsolute(799.2126,1665.3543,1011.8110,1877.9528))

Rule - CLR_FINE_ESCAPE_U_MCU1 Clearance Constraint (Gap=0.15mm) (IsPad And InComponent('U_MCU1')),(IsTrack And InRegionAbsolute(2422.2244,1182.0669,3168.3268,1928.1693))

Rule - CLR_ST67_ANTENNA_BOUNDARY_NO_EXTRA_GAP Clearance Constraint (Gap=0mm) (IsPad And InComponent('U_WIFI1') And ((Name = 'U_WIFI1-25') Or (Name = 'U_WIFI1-26') Or (Name = 'U_WIFI1-27') Or (Name = 'U_WIFI1-28') Or (Name = 'U_WIFI1-29') Or (Name = 'U_WIFI1-30') Or (Name = 'U_WIFI1-31') Or (Name = 'U_WIFI1-32'))),(IsRegion And OnLayer('Keep-Out Layer') And InRegionAbsolute(1739.72440945,2143.26771654,2223.26771654,2340.19685039))

Rule - CLR_FINAL_TT_073 Clearance Constraint (Gap=0.175mm) (IsTrack And InNet('NetL1_2') And InRegionAbsolute(1340.551184,1792.716484,1448.818916,1844.488116)),(IsTrack And InNet('3V3_DIG') And InRegionAbsolute(1340.551184,1792.716484,1448.818916,1844.488116))

Rule - CLR_FINAL_TT_072 Clearance Constraint (Gap=0.175mm) (IsTrack And InNet('VSYS') And InRegionAbsolute(1228.346484,1792.716484,1336.614216,1844.488116)),(IsTrack And InNet('NetL1_1') And InRegionAbsolute(1228.346484,1792.716484,1336.614216,1844.488116))

Rule - CLR_FINAL_TP_071 Clearance Constraint (Gap=0.15mm) (IsTrack And InNet('NetL1_1') And InRegionAbsolute(1320.866184,1792.716484,1336.614216,1844.488116)),(IsPad And (Name = 'UP2-4'))

Rule - CLR_FINAL_TP_070 Clearance Constraint (Gap=0.15mm) (IsTrack And InNet('VSYS') And InRegionAbsolute(1228.346484,1792.716484,1316.929116,1816.929116)),(IsPad And (Name = 'UP2-3'))

Rule - CLR_FINAL_TP_069 Clearance Constraint (Gap=0.15mm) (IsTrack And InNet('3V3_DIG') And InRegionAbsolute(1360.236284,1792.716484,1448.818916,1815.975616)),(IsPad And (Name = 'UP2-2'))

Rule - CLR_FINAL_TP_068 Clearance Constraint (Gap=0.15mm) (IsTrack And InNet('NetL1_2') And InRegionAbsolute(1340.551184,1792.716484,1356.299216,1844.488116)),(IsPad And (Name = 'UP2-1'))

Rule - CLR_FINAL_TP_067 Clearance Constraint (Gap=0.2mm) (IsTrack And InNet('VSYS') And InRegionAbsolute(952.755784,1753.936984,1009.842516,1779.527516)),(IsPad And (Name = 'UP1-9'))

Rule - CLR_FINAL_TP_066 Clearance Constraint (Gap=0.2mm) (IsTrack And InNet('VBAT_CELL') And InRegionAbsolute(811.023584,1773.622084,858.267616,1789.370116)),(IsPad And (Name = 'UP1-1'))

Rule - CLR_FINAL_TP_065 Clearance Constraint (Gap=0.2mm) (IsTrack And InNet('3V3_DIG') And InRegionAbsolute(1389.341784,1633.858284,1416.478916,1815.975616)),(IsPad And (Name = 'RUP_3-1'))

Rule - CLR_FINAL_PP_064 Clearance Constraint (Gap=0.2mm) (IsPad And (Name = 'RUP_3-1')),(IsPad And (Name = 'RUP_3-2'))

Rule - CLR_FINAL_PP_063 Clearance Constraint (Gap=0.175mm) (IsPad And (Name = 'R_KILL_PU-1')),(IsPad And (Name = 'R_KILL_PU-2'))

Rule - CLR_FINAL_PP_062 Clearance Constraint (Gap=0.175mm) (IsPad And (Name = 'R_INT_PULLUP-1')),(IsPad And (Name = 'R_INT_PULLUP-2'))

Rule - CLR_FINAL_PP_061 Clearance Constraint (Gap=0.175mm) (IsPad And (Name = 'R_EN1_BIAS-1')),(IsPad And (Name = 'R_EN1_BIAS-2'))

Rule - CLR_FINAL_PP_060 Clearance Constraint (Gap=0.2mm) (IsPad And (Name = 'R_EN1_1-1')),(IsPad And (Name = 'R_EN1_1-2'))

Rule - CLR_FINAL_PP_059 Clearance Constraint (Gap=0.175mm) (IsPad And (Name = 'R_AL-1')),(IsPad And (Name = 'R_AL-2'))

Rule - CLR_FINAL_PP_058 Clearance Constraint (Gap=0.2mm) (IsPad And (Name = 'R_ADC1-2')),(IsPad And (Name = 'U_MCU1-22'))

Rule - CLR_FINAL_PP_057 Clearance Constraint (Gap=0.175mm) (IsPad And (Name = 'J_USB_C-B4_A9')),(IsPad And (Name = 'J_USB_C-B5'))

Rule - CLR_FINAL_PP_056 Clearance Constraint (Gap=0.175mm) (IsPad And (Name = 'J_USB_C-B1_A12')),(IsPad And (Name = 'J_USB_C-B4_A9'))

Rule - CLR_FINAL_PP_055 Clearance Constraint (Gap=0.175mm) (IsPad And (Name = 'J_USB_C-A4_B9')),(IsPad And (Name = 'J_USB_C-B8'))

Rule - CLR_FINAL_PP_054 Clearance Constraint (Gap=0.175mm) (IsPad And (Name = 'J_USB_C-A1_B12')),(IsPad And (Name = 'J_USB_C-A4_B9'))

Rule - CLR_FINAL_PP_053 Clearance Constraint (Gap=0.2mm) (IsPad And InComponent('J_USB_C') And InRegionAbsolute(632.283598,1963.385598,633.858402,1964.960402)),(IsPad And (Name = 'J_USB_C-A4_B9'))

Rule - CLR_FINAL_PP_052 Clearance Constraint (Gap=0.2mm) (IsPad And InComponent('J_USB_C') And InRegionAbsolute(632.283598,1735.826598,633.858402,1737.401402)),(IsPad And (Name = 'J_USB_C-B4_A9'))

Rule - CLR_FINAL_TP_051 Clearance Constraint (Gap=0.2mm) (IsTrack And InNet('3V3_DIG') And InRegionAbsolute(1389.341784,1633.858284,1405.315016,1815.975616)),(IsPad And (Name = 'CUP4-2'))

Rule - CLR_FINAL_TP_050 Clearance Constraint (Gap=0.2mm) (IsTrack And InNet('3V3_DIG') And InRegionAbsolute(1389.566984,1633.858284,1412.992216,1815.975616)),(IsPad And (Name = 'CUP4_FB-1'))

Rule - CLR_FINAL_PP_049 Clearance Constraint (Gap=0.2mm) (IsPad And (Name = 'CUP4_FB-1')),(IsPad And (Name = 'CUP4_FB-2'))

Rule - CLR_FINAL_PP_048 Clearance Constraint (Gap=0.2mm) (IsPad And (Name = 'CU6_1-1')),(IsPad And (Name = 'CU6_1-2'))

Rule - CLR_FINAL_PP_047 Clearance Constraint (Gap=0.2mm) (IsPad And (Name = 'CU_14-1')),(IsPad And (Name = 'CU_14-2'))

Rule - CLR_FINAL_PP_046 Clearance Constraint (Gap=0.2mm) (IsPad And (Name = 'CU_12-1')),(IsPad And (Name = 'CU_12-2'))

Rule - CLR_FINAL_PP_045 Clearance Constraint (Gap=0.2mm) (IsPad And (Name = 'CU_11-1')),(IsPad And (Name = 'CU_11-2'))

Rule - CLR_FINAL_PP_044 Clearance Constraint (Gap=0.2mm) (IsPad And (Name = 'Cdiv-1')),(IsPad And (Name = 'Cdiv-2'))

Rule - CLR_FINAL_PP_043 Clearance Constraint (Gap=0.2mm) (IsPad And (Name = 'CCU8-1')),(IsPad And (Name = 'CCU8-2'))

Rule - CLR_FINAL_PP_042 Clearance Constraint (Gap=0.2mm) (IsPad And (Name = 'CCU6-1')),(IsPad And (Name = 'CCU6-2'))

Rule - CLR_FINAL_PP_041 Clearance Constraint (Gap=0.2mm) (IsPad And (Name = 'CCU4-1')),(IsPad And (Name = 'CCU4-2'))

Rule - CLR_FINAL_PP_040 Clearance Constraint (Gap=0.2mm) (IsPad And (Name = 'CCU1-1')),(IsPad And (Name = 'CCU1-2'))

Rule - CLR_FINAL_PP_039 Clearance Constraint (Gap=0.2mm) (IsPad And (Name = 'CCU10-1')),(IsPad And (Name = 'CCU10-2'))

Rule - CLR_FINAL_PP_038 Clearance Constraint (Gap=0.2mm) (IsPad And (Name = 'C3_MCU-1')),(IsPad And (Name = 'C3_MCU-2'))

Rule - CLR_FINAL_PP_037 Clearance Constraint (Gap=0.2mm) (IsPad And (Name = 'C1_MCU-1')),(IsPad And (Name = 'C1_MCU-2'))

Rule - CLR_FINAL_PP_036 Clearance Constraint (Gap=0.2mm) (IsPad And (Name = 'C_VDDUSB-1')),(IsPad And (Name = 'C_VDDUSB-2'))

Rule - CLR_FINAL_PP_035 Clearance Constraint (Gap=0.2mm) (IsPad And (Name = 'C_VBAT-1')),(IsPad And (Name = 'C_VBAT-2'))

Rule - CLR_FINAL_PP_034 Clearance Constraint (Gap=0.2mm) (IsPad And (Name = 'C_UV_BYPASS-1')),(IsPad And (Name = 'C_UV_BYPASS-2'))

Rule - CLR_FINAL_PP_033 Clearance Constraint (Gap=0.2mm) (IsPad And (Name = 'C_MCU_VDD5-1')),(IsPad And (Name = 'C_MCU_VDD5-2'))

Rule - CLR_FINAL_PP_032 Clearance Constraint (Gap=0.2mm) (IsPad And (Name = 'C_MCU_VDD4-1')),(IsPad And (Name = 'C_MCU_VDD4-2'))

Rule - CLR_FINAL_PP_031 Clearance Constraint (Gap=0.2mm) (IsPad And (Name = 'C_MCU_VDD3-1')),(IsPad And (Name = 'C_MCU_VDD3-2'))

Rule - CLR_FINAL_PP_030 Clearance Constraint (Gap=0.2mm) (IsPad And (Name = 'C_MCU_VDD2-1')),(IsPad And (Name = 'C_MCU_VDD2-2'))

Rule - CLR_FINAL_PP_029 Clearance Constraint (Gap=0.2mm) (IsPad And (Name = 'C_MCU_VDD1-1')),(IsPad And (Name = 'C_MCU_VDD1-2'))

Rule - CLR_FINAL_TP_028 Clearance Constraint (Gap=0.2mm) (IsTrack And InNet('ADC_EMG5') And InRegionAbsolute(2610.236184,1130.826784,2635.826816,1218.503916)),(IsPad And (Name = 'U_MCU1-30'))

Rule - CLR_FINAL_TP_027 Clearance Constraint (Gap=0.2mm) (IsTrack And InNet('Vservo_1') And InRegionAbsolute(674.212584,922.244084,879.921316,937.992116)),(IsPad And (Name = 'Rservo_1-2'))

Rule - CLR_FINAL_TP_026 Clearance Constraint (Gap=0.2mm) (IsTrack And InNet('Vservo_1') And InRegionAbsolute(674.212584,922.244084,879.921316,937.992116)),(IsPad And (Name = 'Rservo_1-1'))

Rule - CLR_FINAL_PP_025 Clearance Constraint (Gap=0.2mm) (IsPad And (Name = 'RH_5-1')),(IsPad And (Name = 'RH_5-2'))

Rule - CLR_FINAL_PP_024 Clearance Constraint (Gap=0.2mm) (IsPad And (Name = 'RH_4-1')),(IsPad And (Name = 'RH_4-2'))

Rule - CLR_FINAL_PP_023 Clearance Constraint (Gap=0.2mm) (IsPad And (Name = 'RH_3-1')),(IsPad And (Name = 'RH_3-2'))

Rule - CLR_FINAL_PP_022 Clearance Constraint (Gap=0.2mm) (IsPad And (Name = 'RH_2-1')),(IsPad And (Name = 'RH_2-2'))

Rule - CLR_FINAL_PP_021 Clearance Constraint (Gap=0.2mm) (IsPad And (Name = 'RH_1-1')),(IsPad And (Name = 'RH_1-2'))

Rule - CLR_FINAL_PP_020 Clearance Constraint (Gap=0.2mm) (IsPad And (Name = 'R_ADC2-1')),(IsPad And (Name = 'R_ADC3-2'))

Rule - CLR_FINAL_PP_019 Clearance Constraint (Gap=0.2mm) (IsPad And (Name = 'R_ADC1-2')),(IsPad And (Name = 'U_MCU1-24'))

Rule - CLR_FINAL_PP_018 Clearance Constraint (Gap=0.2mm) (IsPad And (Name = 'R_ADC1-1')),(IsPad And (Name = 'U_MCU1-25'))

Rule - CLR_FINAL_PP_017 Clearance Constraint (Gap=0.2mm) (IsPad And (Name = 'R_ADC1-1')),(IsPad And (Name = 'U_MCU1-24'))

Rule - CLR_FINAL_PP_016 Clearance Constraint (Gap=0.2mm) (IsPad And (Name = 'R_ADC1-1')),(IsPad And (Name = 'R_ADC2-2'))

Rule - CLR_FINAL_TP_015 Clearance Constraint (Gap=0.2mm) (IsTrack And InNet('NetINA5_7') And InRegionAbsolute(2892.711784,821.845684,2956.692916,885.826816)),(IsPad And (Name = 'INA5-6'))

Rule - CLR_FINAL_TP_014 Clearance Constraint (Gap=0.2mm) (IsTrack And InNet('NetINA1_7') And InRegionAbsolute(845.467684,821.845684,909.448816,885.826816)),(IsPad And (Name = 'INA1-6'))

Rule - CLR_FINAL_TP_013 Clearance Constraint (Gap=0.2mm) (IsTrack And InNet('NetCL_1_1') And InRegionAbsolute(588.582684,1151.574884,732.283516,1167.322916)),(IsPad And (Name = 'CL_1-2'))

Rule - CLR_FINAL_PP_012 Clearance Constraint (Gap=0.2mm) (IsPad And (Name = 'Cdiv_1-1')),(IsPad And (Name = 'Cdiv_1-2'))

Rule - CLR_FINAL_PP_011 Clearance Constraint (Gap=0.125mm) (IsPad And (Name = 'C_ADC5-1')),(IsPad And (Name = 'C_ADC5-2'))

Rule - CLR_FINAL_PP_010 Clearance Constraint (Gap=0.125mm) (IsPad And (Name = 'C_ADC4-1')),(IsPad And (Name = 'C_ADC4-2'))

Rule - CLR_FINAL_PP_009 Clearance Constraint (Gap=0.125mm) (IsPad And (Name = 'C_ADC3-1')),(IsPad And (Name = 'C_ADC3-2'))

Rule - CLR_FINAL_PP_008 Clearance Constraint (Gap=0.125mm) (IsPad And (Name = 'C_ADC2-1')),(IsPad And (Name = 'C_ADC2-2'))

Rule - CLR_FINAL_PP_007 Clearance Constraint (Gap=0.125mm) (IsPad And (Name = 'C_ADC1-1')),(IsPad And (Name = 'C_ADC1-2'))

Rule - CLR_FINAL_TP_006 Clearance Constraint (Gap=0.15mm) (IsTrack And InNet('NetL1_2') And InRegionAbsolute(1340.551184,1792.716484,1356.299216,1844.488116)),(IsPad And (Name = 'UP2-3'))

Rule - CLR_FINAL_TP_005 Clearance Constraint (Gap=0.15mm) (IsTrack And InNet('NetL1_1') And InRegionAbsolute(1320.866184,1792.716484,1336.614216,1844.488116)),(IsPad And (Name = 'UP2-2'))

Rule - CLR_FINAL_VP_004 Clearance Constraint (Gap=0.175mm) (IsVia And InNet('GND') And InRegionAbsolute(2657.086299,1201.456299,2657.873701,1202.243701)),(IsPad And (Name = 'U_MCU1-31'))

Rule - CLR_FINAL_PP_003 Clearance Constraint (Gap=0.175mm) (IsPad And (Name = 'R_SHDN_G-1')),(IsPad And (Name = 'R_SHDN_G-2'))

Rule - CLR_FINAL_PP_002 Clearance Constraint (Gap=0.175mm) (IsPad And InComponent('J_USB_C') And InRegionAbsolute(632.283598,1963.385598,633.858402,1964.960402)),(IsPad And (Name = 'J_USB_C-A1_B12'))

Rule - CLR_FINAL_PP_001 Clearance Constraint (Gap=0.175mm) (IsPad And InComponent('J_USB_C') And InRegionAbsolute(632.283598,1735.826598,633.858402,1737.401402)),(IsPad And (Name = 'J_USB_C-B1_A12'))

Rule - CLR_PADS_J_FPC5_010 Clearance Constraint (Gap=0.1mm) (IsPad And InComponent('J_FPC5')),(IsPad And InComponent('J_FPC5'))

Rule - CLR_PADS_J_FPC4_010 Clearance Constraint (Gap=0.1mm) (IsPad And InComponent('J_FPC4')),(IsPad And InComponent('J_FPC4'))

Rule - CLR_PADS_J_FPC3_010 Clearance Constraint (Gap=0.1mm) (IsPad And InComponent('J_FPC3')),(IsPad And InComponent('J_FPC3'))

Rule - CLR_PADS_J_FPC2_010 Clearance Constraint (Gap=0.1mm) (IsPad And InComponent('J_FPC2')),(IsPad And InComponent('J_FPC2'))

Rule - CLR_PADS_J_FPC1_010 Clearance Constraint (Gap=0.1mm) (IsPad And InComponent('J_FPC1')),(IsPad And InComponent('J_FPC1'))

Rule - CLR_PADS_UP4_010 Clearance Constraint (Gap=0.1mm) (IsPad And InComponent('UP4')),(IsPad And InComponent('UP4'))

Rule - CLR_PADS_UP2_010 Clearance Constraint (Gap=0.1mm) (IsPad And InComponent('UP2')),(IsPad And InComponent('UP2'))

Rule - CLR_PADS_UP1_010 Clearance Constraint (Gap=0.1mm) (IsPad And InComponent('UP1')),(IsPad And InComponent('UP1'))

Rule - CLR_PADS_U_MCU1_010 Clearance Constraint (Gap=0.1mm) (IsPad And InComponent('U_MCU1')),(IsPad And InComponent('U_MCU1'))

Rule - CLR_POWER_025 Clearance Constraint (Gap=0.25mm) (InNetClass('EMG_POWER')),(All)

Rule - CLR_ANALOG_025 Clearance Constraint (Gap=0.25mm) (InNetClass('EMG_ANALOG') Or InNetClass('EMG_ADC') Or InNetClass('EMG_REFERENCE')),(All)

Rule - CLR_GENERAL_020 Clearance Constraint (Gap=0.2mm) (All),(All)

Rule - Clearance Clearance Constraint (Gap=0.254mm) (All),(All)

Back to top

Fanout Styles | Affected Components
Rule - Fanout_Default Fanout Control Rule ( (All) ) | 10
Rule - Fanout_Small Fanout Control Rule ( ((CompPinCount < 5)) ) | 207
Rule - Fanout_SOIC Fanout Control Rule ( (IsSOIC) ) | 11
Rule - Fanout_LCC Fanout Control Rule ( (IsLCC) ) | 3

Back to top

Routing Directions Layer Name | Direction
L1 TOP | Automatic
L2 GND | Automatic
L3 POWER SIGNAL | Automatic
L4 BOTTOM GND | Automatic

Back to top

Drill Layer Pairs

L1 TOP - L4 BOTTOM GND

Back to top

Net Topologies | Affected Nets
Rule - RoutingTopology Routing Topology Rule(Topology=Shortest) (All) | 136

Back to top

Net Layers | Affected Nets
Rule - RL_BOTTOM_PAD_NETS Routing Layers(InNet('3V0_ANA') Or InNet('DRL_AMP_OUT') Or InNet('DRL_LIMITED') Or InNet('DRL_LIMIT_MID') Or InNet('DRL_SUM') Or InNet('NetJ_REF_1') Or InNet('VREF_B_SRC') Or InNet('Va_1') Or InNet('Va_2') Or InNet('Va_3') Or InNet('Va_4') Or InNet('Va_5') Or InNet('Vb_1') Or InNet('Vb_2') Or InNet('Vb_3') Or InNet('Vb_4') Or InNet('Vb_5') Or InNet('Vc_1') Or InNet('Vc_2') Or InNet('Vc_3') Or InNet('Vc_4') Or InNet('Vc_5')) | 22
Rule - RoutingLayers Routing Layers(All) | 114

Back to top

SMD Neckdown Rules | Affected Pads
Hint: no default SMDNeckDown rule exists. | 781

Back to top

Unroutable pads

Error : Pad J_FPC5-3 Appears to be unroutable. Violation against Rule - CLR_BK13_ESCAPE_J_FPC5 Clearance Constraint (Gap=0.13mm) (InRegionAbsolute(2755.9055,409.4488,3035.4331,594.4882) And (InComponent('J_FPC5') Or InNet('3V0_ANA') Or InNet('GND') Or InNet('NetJ_FPC5_8') Or InNet('Va_5') Or InNet('Vb_5') Or InNet('Vc_5'))),(InRegionAbsolute(2755.9055,409.4488,3035.4331,594.4882) And (InComponent('J_FPC5') Or InNet('3V0_ANA') Or InNet('GND') Or InNet('NetJ_FPC5_8') Or InNet('Va_5') Or InNet('Vb_5') Or InNet('Vc_5'))) Detected.

Error : Pad J_FPC5-4 Appears to be unroutable. Violation against Rule - CLR_BK13_ESCAPE_J_FPC5 Clearance Constraint (Gap=0.13mm) (InRegionAbsolute(2755.9055,409.4488,3035.4331,594.4882) And (InComponent('J_FPC5') Or InNet('3V0_ANA') Or InNet('GND') Or InNet('NetJ_FPC5_8') Or InNet('Va_5') Or InNet('Vb_5') Or InNet('Vc_5'))),(InRegionAbsolute(2755.9055,409.4488,3035.4331,594.4882) And (InComponent('J_FPC5') Or InNet('3V0_ANA') Or InNet('GND') Or InNet('NetJ_FPC5_8') Or InNet('Va_5') Or InNet('Vb_5') Or InNet('Vc_5'))) Detected.

Error : Pad J_FPC5-5 Appears to be unroutable. Violation against Rule - CLR_BK13_ESCAPE_J_FPC5 Clearance Constraint (Gap=0.13mm) (InRegionAbsolute(2755.9055,409.4488,3035.4331,594.4882) And (InComponent('J_FPC5') Or InNet('3V0_ANA') Or InNet('GND') Or InNet('NetJ_FPC5_8') Or InNet('Va_5') Or InNet('Vb_5') Or InNet('Vc_5'))),(InRegionAbsolute(2755.9055,409.4488,3035.4331,594.4882) And (InComponent('J_FPC5') Or InNet('3V0_ANA') Or InNet('GND') Or InNet('NetJ_FPC5_8') Or InNet('Va_5') Or InNet('Vb_5') Or InNet('Vc_5'))) Detected.

Error : Pad J_FPC5-2 Appears to be unroutable. Violation against Rule - CLR_BK13_ESCAPE_J_FPC5 Clearance Constraint (Gap=0.13mm) (InRegionAbsolute(2755.9055,409.4488,3035.4331,594.4882) And (InComponent('J_FPC5') Or InNet('3V0_ANA') Or InNet('GND') Or InNet('NetJ_FPC5_8') Or InNet('Va_5') Or InNet('Vb_5') Or InNet('Vc_5'))),(InRegionAbsolute(2755.9055,409.4488,3035.4331,594.4882) And (InComponent('J_FPC5') Or InNet('3V0_ANA') Or InNet('GND') Or InNet('NetJ_FPC5_8') Or InNet('Va_5') Or InNet('Vb_5') Or InNet('Vc_5'))) Detected.

Error : Pad J_FPC5-1 Appears to be unroutable. Violation against Rule - CLR_BK13_ESCAPE_J_FPC5 Clearance Constraint (Gap=0.13mm) (InRegionAbsolute(2755.9055,409.4488,3035.4331,594.4882) And (InComponent('J_FPC5') Or InNet('3V0_ANA') Or InNet('GND') Or InNet('NetJ_FPC5_8') Or InNet('Va_5') Or InNet('Vb_5') Or InNet('Vc_5'))),(InRegionAbsolute(2755.9055,409.4488,3035.4331,594.4882) And (InComponent('J_FPC5') Or InNet('3V0_ANA') Or InNet('GND') Or InNet('NetJ_FPC5_8') Or InNet('Va_5') Or InNet('Vb_5') Or InNet('Vc_5'))) Detected.

Error : Pad J_FPC5-8 Appears to be unroutable. Violation against Rule - CLR_BK13_ESCAPE_J_FPC5 Clearance Constraint (Gap=0.13mm) (InRegionAbsolute(2755.9055,409.4488,3035.4331,594.4882) And (InComponent('J_FPC5') Or InNet('3V0_ANA') Or InNet('GND') Or InNet('NetJ_FPC5_8') Or InNet('Va_5') Or InNet('Vb_5') Or InNet('Vc_5'))),(InRegionAbsolute(2755.9055,409.4488,3035.4331,594.4882) And (InComponent('J_FPC5') Or InNet('3V0_ANA') Or InNet('GND') Or InNet('NetJ_FPC5_8') Or InNet('Va_5') Or InNet('Vb_5') Or InNet('Vc_5'))) Detected.

Error : Pad J_FPC5-9 Appears to be unroutable. Violation against Rule - CLR_BK13_ESCAPE_J_FPC5 Clearance Constraint (Gap=0.13mm) (InRegionAbsolute(2755.9055,409.4488,3035.4331,594.4882) And (InComponent('J_FPC5') Or InNet('3V0_ANA') Or InNet('GND') Or InNet('NetJ_FPC5_8') Or InNet('Va_5') Or InNet('Vb_5') Or InNet('Vc_5'))),(InRegionAbsolute(2755.9055,409.4488,3035.4331,594.4882) And (InComponent('J_FPC5') Or InNet('3V0_ANA') Or InNet('GND') Or InNet('NetJ_FPC5_8') Or InNet('Va_5') Or InNet('Vb_5') Or InNet('Vc_5'))) Detected.

Error : Pad J_FPC5-7 Appears to be unroutable. Violation against Rule - CLR_BK13_ESCAPE_J_FPC5 Clearance Constraint (Gap=0.13mm) (InRegionAbsolute(2755.9055,409.4488,3035.4331,594.4882) And (InComponent('J_FPC5') Or InNet('3V0_ANA') Or InNet('GND') Or InNet('NetJ_FPC5_8') Or InNet('Va_5') Or InNet('Vb_5') Or InNet('Vc_5'))),(InRegionAbsolute(2755.9055,409.4488,3035.4331,594.4882) And (InComponent('J_FPC5') Or InNet('3V0_ANA') Or InNet('GND') Or InNet('NetJ_FPC5_8') Or InNet('Va_5') Or InNet('Vb_5') Or InNet('Vc_5'))) Detected.

Error : Pad J_FPC5-6 Appears to be unroutable. Violation against Rule - CLR_BK13_ESCAPE_J_FPC5 Clearance Constraint (Gap=0.13mm) (InRegionAbsolute(2755.9055,409.4488,3035.4331,594.4882) And (InComponent('J_FPC5') Or InNet('3V0_ANA') Or InNet('GND') Or InNet('NetJ_FPC5_8') Or InNet('Va_5') Or InNet('Vb_5') Or InNet('Vc_5'))),(InRegionAbsolute(2755.9055,409.4488,3035.4331,594.4882) And (InComponent('J_FPC5') Or InNet('3V0_ANA') Or InNet('GND') Or InNet('NetJ_FPC5_8') Or InNet('Va_5') Or InNet('Vb_5') Or InNet('Vc_5'))) Detected.

Error : Pad J_FPC5-P1_2 Appears to be unroutable. Violation against Rule - CLR_BK13_ESCAPE_J_FPC5 Clearance Constraint (Gap=0.13mm) (InRegionAbsolute(2755.9055,409.4488,3035.4331,594.4882) And (InComponent('J_FPC5') Or InNet('3V0_ANA') Or InNet('GND') Or InNet('NetJ_FPC5_8') Or InNet('Va_5') Or InNet('Vb_5') Or InNet('Vc_5'))),(InRegionAbsolute(2755.9055,409.4488,3035.4331,594.4882) And (InComponent('J_FPC5') Or InNet('3V0_ANA') Or InNet('GND') Or InNet('NetJ_FPC5_8') Or InNet('Va_5') Or InNet('Vb_5') Or InNet('Vc_5'))) Detected.

Error : Pad J_FPC5-P1_1 Appears to be unroutable. Violation against Rule - CLR_BK13_ESCAPE_J_FPC5 Clearance Constraint (Gap=0.13mm) (InRegionAbsolute(2755.9055,409.4488,3035.4331,594.4882) And (InComponent('J_FPC5') Or InNet('3V0_ANA') Or InNet('GND') Or InNet('NetJ_FPC5_8') Or InNet('Va_5') Or InNet('Vb_5') Or InNet('Vc_5'))),(InRegionAbsolute(2755.9055,409.4488,3035.4331,594.4882) And (InComponent('J_FPC5') Or InNet('3V0_ANA') Or InNet('GND') Or InNet('NetJ_FPC5_8') Or InNet('Va_5') Or InNet('Vb_5') Or InNet('Vc_5'))) Detected.

Error : Pad J_FPC5-P2_1 Appears to be unroutable. Violation against Rule - CLR_BK13_ESCAPE_J_FPC5 Clearance Constraint (Gap=0.13mm) (InRegionAbsolute(2755.9055,409.4488,3035.4331,594.4882) And (InComponent('J_FPC5') Or InNet('3V0_ANA') Or InNet('GND') Or InNet('NetJ_FPC5_8') Or InNet('Va_5') Or InNet('Vb_5') Or InNet('Vc_5'))),(InRegionAbsolute(2755.9055,409.4488,3035.4331,594.4882) And (InComponent('J_FPC5') Or InNet('3V0_ANA') Or InNet('GND') Or InNet('NetJ_FPC5_8') Or InNet('Va_5') Or InNet('Vb_5') Or InNet('Vc_5'))) Detected.

Error : Pad J_FPC5-P2_2 Appears to be unroutable. Violation against Rule - CLR_BK13_ESCAPE_J_FPC5 Clearance Constraint (Gap=0.13mm) (InRegionAbsolute(2755.9055,409.4488,3035.4331,594.4882) And (InComponent('J_FPC5') Or InNet('3V0_ANA') Or InNet('GND') Or InNet('NetJ_FPC5_8') Or InNet('Va_5') Or InNet('Vb_5') Or InNet('Vc_5'))),(InRegionAbsolute(2755.9055,409.4488,3035.4331,594.4882) And (InComponent('J_FPC5') Or InNet('3V0_ANA') Or InNet('GND') Or InNet('NetJ_FPC5_8') Or InNet('Va_5') Or InNet('Vb_5') Or InNet('Vc_5'))) Detected.

Error : Pad J_FPC5-P2_3 Appears to be unroutable. Violation against Rule - CLR_BK13_ESCAPE_J_FPC5 Clearance Constraint (Gap=0.13mm) (InRegionAbsolute(2755.9055,409.4488,3035.4331,594.4882) And (InComponent('J_FPC5') Or InNet('3V0_ANA') Or InNet('GND') Or InNet('NetJ_FPC5_8') Or InNet('Va_5') Or InNet('Vb_5') Or InNet('Vc_5'))),(InRegionAbsolute(2755.9055,409.4488,3035.4331,594.4882) And (InComponent('J_FPC5') Or InNet('3V0_ANA') Or InNet('GND') Or InNet('NetJ_FPC5_8') Or InNet('Va_5') Or InNet('Vb_5') Or InNet('Vc_5'))) Detected.

Error : Pad J_FPC5-P1_3 Appears to be unroutable. Violation against Rule - CLR_BK13_ESCAPE_J_FPC5 Clearance Constraint (Gap=0.13mm) (InRegionAbsolute(2755.9055,409.4488,3035.4331,594.4882) And (InComponent('J_FPC5') Or InNet('3V0_ANA') Or InNet('GND') Or InNet('NetJ_FPC5_8') Or InNet('Va_5') Or InNet('Vb_5') Or InNet('Vc_5'))),(InRegionAbsolute(2755.9055,409.4488,3035.4331,594.4882) And (InComponent('J_FPC5') Or InNet('3V0_ANA') Or InNet('GND') Or InNet('NetJ_FPC5_8') Or InNet('Va_5') Or InNet('Vb_5') Or InNet('Vc_5'))) Detected.

Error : Pad J_FPC5-10 Appears to be unroutable. Violation against Rule - CLR_BK13_ESCAPE_J_FPC5 Clearance Constraint (Gap=0.13mm) (InRegionAbsolute(2755.9055,409.4488,3035.4331,594.4882) And (InComponent('J_FPC5') Or InNet('3V0_ANA') Or InNet('GND') Or InNet('NetJ_FPC5_8') Or InNet('Va_5') Or InNet('Vb_5') Or InNet('Vc_5'))),(InRegionAbsolute(2755.9055,409.4488,3035.4331,594.4882) And (InComponent('J_FPC5') Or InNet('3V0_ANA') Or InNet('GND') Or InNet('NetJ_FPC5_8') Or InNet('Va_5') Or InNet('Vb_5') Or InNet('Vc_5'))) Detected.

Error : Pad J_FPC4-3 Appears to be unroutable. Violation against Rule - CLR_BK13_ESCAPE_J_FPC4 Clearance Constraint (Gap=0.13mm) (InRegionAbsolute(2244.0945,409.4488,2523.6220,594.4882) And (InComponent('J_FPC4') Or InNet('3V0_ANA') Or InNet('GND') Or InNet('NetJ_FPC4_8') Or InNet('Va_4') Or InNet('Vb_4') Or InNet('Vc_4'))),(InRegionAbsolute(2244.0945,409.4488,2523.6220,594.4882) And (InComponent('J_FPC4') Or InNet('3V0_ANA') Or InNet('GND') Or InNet('NetJ_FPC4_8') Or InNet('Va_4') Or InNet('Vb_4') Or InNet('Vc_4'))) Detected.

Error : Pad J_FPC4-4 Appears to be unroutable. Violation against Rule - CLR_BK13_ESCAPE_J_FPC4 Clearance Constraint (Gap=0.13mm) (InRegionAbsolute(2244.0945,409.4488,2523.6220,594.4882) And (InComponent('J_FPC4') Or InNet('3V0_ANA') Or InNet('GND') Or InNet('NetJ_FPC4_8') Or InNet('Va_4') Or InNet('Vb_4') Or InNet('Vc_4'))),(InRegionAbsolute(2244.0945,409.4488,2523.6220,594.4882) And (InComponent('J_FPC4') Or InNet('3V0_ANA') Or InNet('GND') Or InNet('NetJ_FPC4_8') Or InNet('Va_4') Or InNet('Vb_4') Or InNet('Vc_4'))) Detected.

Error : Pad J_FPC4-5 Appears to be unroutable. Violation against Rule - CLR_BK13_ESCAPE_J_FPC4 Clearance Constraint (Gap=0.13mm) (InRegionAbsolute(2244.0945,409.4488,2523.6220,594.4882) And (InComponent('J_FPC4') Or InNet('3V0_ANA') Or InNet('GND') Or InNet('NetJ_FPC4_8') Or InNet('Va_4') Or InNet('Vb_4') Or InNet('Vc_4'))),(InRegionAbsolute(2244.0945,409.4488,2523.6220,594.4882) And (InComponent('J_FPC4') Or InNet('3V0_ANA') Or InNet('GND') Or InNet('NetJ_FPC4_8') Or InNet('Va_4') Or InNet('Vb_4') Or InNet('Vc_4'))) Detected.

Error : Pad J_FPC4-2 Appears to be unroutable. Violation against Rule - CLR_BK13_ESCAPE_J_FPC4 Clearance Constraint (Gap=0.13mm) (InRegionAbsolute(2244.0945,409.4488,2523.6220,594.4882) And (InComponent('J_FPC4') Or InNet('3V0_ANA') Or InNet('GND') Or InNet('NetJ_FPC4_8') Or InNet('Va_4') Or InNet('Vb_4') Or InNet('Vc_4'))),(InRegionAbsolute(2244.0945,409.4488,2523.6220,594.4882) And (InComponent('J_FPC4') Or InNet('3V0_ANA') Or InNet('GND') Or InNet('NetJ_FPC4_8') Or InNet('Va_4') Or InNet('Vb_4') Or InNet('Vc_4'))) Detected.

Error : Pad J_FPC4-1 Appears to be unroutable. Violation against Rule - CLR_BK13_ESCAPE_J_FPC4 Clearance Constraint (Gap=0.13mm) (InRegionAbsolute(2244.0945,409.4488,2523.6220,594.4882) And (InComponent('J_FPC4') Or InNet('3V0_ANA') Or InNet('GND') Or InNet('NetJ_FPC4_8') Or InNet('Va_4') Or InNet('Vb_4') Or InNet('Vc_4'))),(InRegionAbsolute(2244.0945,409.4488,2523.6220,594.4882) And (InComponent('J_FPC4') Or InNet('3V0_ANA') Or InNet('GND') Or InNet('NetJ_FPC4_8') Or InNet('Va_4') Or InNet('Vb_4') Or InNet('Vc_4'))) Detected.

Error : Pad J_FPC4-8 Appears to be unroutable. Violation against Rule - CLR_BK13_ESCAPE_J_FPC4 Clearance Constraint (Gap=0.13mm) (InRegionAbsolute(2244.0945,409.4488,2523.6220,594.4882) And (InComponent('J_FPC4') Or InNet('3V0_ANA') Or InNet('GND') Or InNet('NetJ_FPC4_8') Or InNet('Va_4') Or InNet('Vb_4') Or InNet('Vc_4'))),(InRegionAbsolute(2244.0945,409.4488,2523.6220,594.4882) And (InComponent('J_FPC4') Or InNet('3V0_ANA') Or InNet('GND') Or InNet('NetJ_FPC4_8') Or InNet('Va_4') Or InNet('Vb_4') Or InNet('Vc_4'))) Detected.

Error : Pad J_FPC4-9 Appears to be unroutable. Violation against Rule - CLR_BK13_ESCAPE_J_FPC4 Clearance Constraint (Gap=0.13mm) (InRegionAbsolute(2244.0945,409.4488,2523.6220,594.4882) And (InComponent('J_FPC4') Or InNet('3V0_ANA') Or InNet('GND') Or InNet('NetJ_FPC4_8') Or InNet('Va_4') Or InNet('Vb_4') Or InNet('Vc_4'))),(InRegionAbsolute(2244.0945,409.4488,2523.6220,594.4882) And (InComponent('J_FPC4') Or InNet('3V0_ANA') Or InNet('GND') Or InNet('NetJ_FPC4_8') Or InNet('Va_4') Or InNet('Vb_4') Or InNet('Vc_4'))) Detected.

Error : Pad J_FPC4-7 Appears to be unroutable. Violation against Rule - CLR_BK13_ESCAPE_J_FPC4 Clearance Constraint (Gap=0.13mm) (InRegionAbsolute(2244.0945,409.4488,2523.6220,594.4882) And (InComponent('J_FPC4') Or InNet('3V0_ANA') Or InNet('GND') Or InNet('NetJ_FPC4_8') Or InNet('Va_4') Or InNet('Vb_4') Or InNet('Vc_4'))),(InRegionAbsolute(2244.0945,409.4488,2523.6220,594.4882) And (InComponent('J_FPC4') Or InNet('3V0_ANA') Or InNet('GND') Or InNet('NetJ_FPC4_8') Or InNet('Va_4') Or InNet('Vb_4') Or InNet('Vc_4'))) Detected.

Error : Pad J_FPC4-6 Appears to be unroutable. Violation against Rule - CLR_BK13_ESCAPE_J_FPC4 Clearance Constraint (Gap=0.13mm) (InRegionAbsolute(2244.0945,409.4488,2523.6220,594.4882) And (InComponent('J_FPC4') Or InNet('3V0_ANA') Or InNet('GND') Or InNet('NetJ_FPC4_8') Or InNet('Va_4') Or InNet('Vb_4') Or InNet('Vc_4'))),(InRegionAbsolute(2244.0945,409.4488,2523.6220,594.4882) And (InComponent('J_FPC4') Or InNet('3V0_ANA') Or InNet('GND') Or InNet('NetJ_FPC4_8') Or InNet('Va_4') Or InNet('Vb_4') Or InNet('Vc_4'))) Detected.

Error : Pad J_FPC4-P1_2 Appears to be unroutable. Violation against Rule - CLR_BK13_ESCAPE_J_FPC4 Clearance Constraint (Gap=0.13mm) (InRegionAbsolute(2244.0945,409.4488,2523.6220,594.4882) And (InComponent('J_FPC4') Or InNet('3V0_ANA') Or InNet('GND') Or InNet('NetJ_FPC4_8') Or InNet('Va_4') Or InNet('Vb_4') Or InNet('Vc_4'))),(InRegionAbsolute(2244.0945,409.4488,2523.6220,594.4882) And (InComponent('J_FPC4') Or InNet('3V0_ANA') Or InNet('GND') Or InNet('NetJ_FPC4_8') Or InNet('Va_4') Or InNet('Vb_4') Or InNet('Vc_4'))) Detected.

Error : Pad J_FPC4-P1_1 Appears to be unroutable. Violation against Rule - CLR_BK13_ESCAPE_J_FPC4 Clearance Constraint (Gap=0.13mm) (InRegionAbsolute(2244.0945,409.4488,2523.6220,594.4882) And (InComponent('J_FPC4') Or InNet('3V0_ANA') Or InNet('GND') Or InNet('NetJ_FPC4_8') Or InNet('Va_4') Or InNet('Vb_4') Or InNet('Vc_4'))),(InRegionAbsolute(2244.0945,409.4488,2523.6220,594.4882) And (InComponent('J_FPC4') Or InNet('3V0_ANA') Or InNet('GND') Or InNet('NetJ_FPC4_8') Or InNet('Va_4') Or InNet('Vb_4') Or InNet('Vc_4'))) Detected.

Error : Pad J_FPC4-P2_1 Appears to be unroutable. Violation against Rule - CLR_BK13_ESCAPE_J_FPC4 Clearance Constraint (Gap=0.13mm) (InRegionAbsolute(2244.0945,409.4488,2523.6220,594.4882) And (InComponent('J_FPC4') Or InNet('3V0_ANA') Or InNet('GND') Or InNet('NetJ_FPC4_8') Or InNet('Va_4') Or InNet('Vb_4') Or InNet('Vc_4'))),(InRegionAbsolute(2244.0945,409.4488,2523.6220,594.4882) And (InComponent('J_FPC4') Or InNet('3V0_ANA') Or InNet('GND') Or InNet('NetJ_FPC4_8') Or InNet('Va_4') Or InNet('Vb_4') Or InNet('Vc_4'))) Detected.

Error : Pad J_FPC4-P2_2 Appears to be unroutable. Violation against Rule - CLR_BK13_ESCAPE_J_FPC4 Clearance Constraint (Gap=0.13mm) (InRegionAbsolute(2244.0945,409.4488,2523.6220,594.4882) And (InComponent('J_FPC4') Or InNet('3V0_ANA') Or InNet('GND') Or InNet('NetJ_FPC4_8') Or InNet('Va_4') Or InNet('Vb_4') Or InNet('Vc_4'))),(InRegionAbsolute(2244.0945,409.4488,2523.6220,594.4882) And (InComponent('J_FPC4') Or InNet('3V0_ANA') Or InNet('GND') Or InNet('NetJ_FPC4_8') Or InNet('Va_4') Or InNet('Vb_4') Or InNet('Vc_4'))) Detected.

Error : Pad J_FPC4-P2_3 Appears to be unroutable. Violation against Rule - CLR_BK13_ESCAPE_J_FPC4 Clearance Constraint (Gap=0.13mm) (InRegionAbsolute(2244.0945,409.4488,2523.6220,594.4882) And (InComponent('J_FPC4') Or InNet('3V0_ANA') Or InNet('GND') Or InNet('NetJ_FPC4_8') Or InNet('Va_4') Or InNet('Vb_4') Or InNet('Vc_4'))),(InRegionAbsolute(2244.0945,409.4488,2523.6220,594.4882) And (InComponent('J_FPC4') Or InNet('3V0_ANA') Or InNet('GND') Or InNet('NetJ_FPC4_8') Or InNet('Va_4') Or InNet('Vb_4') Or InNet('Vc_4'))) Detected.

Error : Pad J_FPC4-P1_3 Appears to be unroutable. Violation against Rule - CLR_BK13_ESCAPE_J_FPC4 Clearance Constraint (Gap=0.13mm) (InRegionAbsolute(2244.0945,409.4488,2523.6220,594.4882) And (InComponent('J_FPC4') Or InNet('3V0_ANA') Or InNet('GND') Or InNet('NetJ_FPC4_8') Or InNet('Va_4') Or InNet('Vb_4') Or InNet('Vc_4'))),(InRegionAbsolute(2244.0945,409.4488,2523.6220,594.4882) And (InComponent('J_FPC4') Or InNet('3V0_ANA') Or InNet('GND') Or InNet('NetJ_FPC4_8') Or InNet('Va_4') Or InNet('Vb_4') Or InNet('Vc_4'))) Detected.

Error : Pad J_FPC4-10 Appears to be unroutable. Violation against Rule - CLR_BK13_ESCAPE_J_FPC4 Clearance Constraint (Gap=0.13mm) (InRegionAbsolute(2244.0945,409.4488,2523.6220,594.4882) And (InComponent('J_FPC4') Or InNet('3V0_ANA') Or InNet('GND') Or InNet('NetJ_FPC4_8') Or InNet('Va_4') Or InNet('Vb_4') Or InNet('Vc_4'))),(InRegionAbsolute(2244.0945,409.4488,2523.6220,594.4882) And (InComponent('J_FPC4') Or InNet('3V0_ANA') Or InNet('GND') Or InNet('NetJ_FPC4_8') Or InNet('Va_4') Or InNet('Vb_4') Or InNet('Vc_4'))) Detected.

Error : Pad J_FPC3-3 Appears to be unroutable. Violation against Rule - CLR_BK13_ESCAPE_J_FPC3 Clearance Constraint (Gap=0.13mm) (InRegionAbsolute(1732.2835,409.4488,2011.8110,594.4882) And (InComponent('J_FPC3') Or InNet('3V0_ANA') Or InNet('GND') Or InNet('NetJ_FPC3_8') Or InNet('Va_3') Or InNet('Vb_3') Or InNet('Vc_3'))),(InRegionAbsolute(1732.2835,409.4488,2011.8110,594.4882) And (InComponent('J_FPC3') Or InNet('3V0_ANA') Or InNet('GND') Or InNet('NetJ_FPC3_8') Or InNet('Va_3') Or InNet('Vb_3') Or InNet('Vc_3'))) Detected.

Error : Pad J_FPC3-4 Appears to be unroutable. Violation against Rule - CLR_BK13_ESCAPE_J_FPC3 Clearance Constraint (Gap=0.13mm) (InRegionAbsolute(1732.2835,409.4488,2011.8110,594.4882) And (InComponent('J_FPC3') Or InNet('3V0_ANA') Or InNet('GND') Or InNet('NetJ_FPC3_8') Or InNet('Va_3') Or InNet('Vb_3') Or InNet('Vc_3'))),(InRegionAbsolute(1732.2835,409.4488,2011.8110,594.4882) And (InComponent('J_FPC3') Or InNet('3V0_ANA') Or InNet('GND') Or InNet('NetJ_FPC3_8') Or InNet('Va_3') Or InNet('Vb_3') Or InNet('Vc_3'))) Detected.

Error : Pad J_FPC3-5 Appears to be unroutable. Violation against Rule - CLR_BK13_ESCAPE_J_FPC3 Clearance Constraint (Gap=0.13mm) (InRegionAbsolute(1732.2835,409.4488,2011.8110,594.4882) And (InComponent('J_FPC3') Or InNet('3V0_ANA') Or InNet('GND') Or InNet('NetJ_FPC3_8') Or InNet('Va_3') Or InNet('Vb_3') Or InNet('Vc_3'))),(InRegionAbsolute(1732.2835,409.4488,2011.8110,594.4882) And (InComponent('J_FPC3') Or InNet('3V0_ANA') Or InNet('GND') Or InNet('NetJ_FPC3_8') Or InNet('Va_3') Or InNet('Vb_3') Or InNet('Vc_3'))) Detected.

Error : Pad J_FPC3-2 Appears to be unroutable. Violation against Rule - CLR_BK13_ESCAPE_J_FPC3 Clearance Constraint (Gap=0.13mm) (InRegionAbsolute(1732.2835,409.4488,2011.8110,594.4882) And (InComponent('J_FPC3') Or InNet('3V0_ANA') Or InNet('GND') Or InNet('NetJ_FPC3_8') Or InNet('Va_3') Or InNet('Vb_3') Or InNet('Vc_3'))),(InRegionAbsolute(1732.2835,409.4488,2011.8110,594.4882) And (InComponent('J_FPC3') Or InNet('3V0_ANA') Or InNet('GND') Or InNet('NetJ_FPC3_8') Or InNet('Va_3') Or InNet('Vb_3') Or InNet('Vc_3'))) Detected.

Error : Pad J_FPC3-1 Appears to be unroutable. Violation against Rule - CLR_BK13_ESCAPE_J_FPC3 Clearance Constraint (Gap=0.13mm) (InRegionAbsolute(1732.2835,409.4488,2011.8110,594.4882) And (InComponent('J_FPC3') Or InNet('3V0_ANA') Or InNet('GND') Or InNet('NetJ_FPC3_8') Or InNet('Va_3') Or InNet('Vb_3') Or InNet('Vc_3'))),(InRegionAbsolute(1732.2835,409.4488,2011.8110,594.4882) And (InComponent('J_FPC3') Or InNet('3V0_ANA') Or InNet('GND') Or InNet('NetJ_FPC3_8') Or InNet('Va_3') Or InNet('Vb_3') Or InNet('Vc_3'))) Detected.

Error : Pad J_FPC3-8 Appears to be unroutable. Violation against Rule - CLR_BK13_ESCAPE_J_FPC3 Clearance Constraint (Gap=0.13mm) (InRegionAbsolute(1732.2835,409.4488,2011.8110,594.4882) And (InComponent('J_FPC3') Or InNet('3V0_ANA') Or InNet('GND') Or InNet('NetJ_FPC3_8') Or InNet('Va_3') Or InNet('Vb_3') Or InNet('Vc_3'))),(InRegionAbsolute(1732.2835,409.4488,2011.8110,594.4882) And (InComponent('J_FPC3') Or InNet('3V0_ANA') Or InNet('GND') Or InNet('NetJ_FPC3_8') Or InNet('Va_3') Or InNet('Vb_3') Or InNet('Vc_3'))) Detected.

Error : Pad J_FPC3-9 Appears to be unroutable. Violation against Rule - CLR_BK13_ESCAPE_J_FPC3 Clearance Constraint (Gap=0.13mm) (InRegionAbsolute(1732.2835,409.4488,2011.8110,594.4882) And (InComponent('J_FPC3') Or InNet('3V0_ANA') Or InNet('GND') Or InNet('NetJ_FPC3_8') Or InNet('Va_3') Or InNet('Vb_3') Or InNet('Vc_3'))),(InRegionAbsolute(1732.2835,409.4488,2011.8110,594.4882) And (InComponent('J_FPC3') Or InNet('3V0_ANA') Or InNet('GND') Or InNet('NetJ_FPC3_8') Or InNet('Va_3') Or InNet('Vb_3') Or InNet('Vc_3'))) Detected.

Error : Pad J_FPC3-7 Appears to be unroutable. Violation against Rule - CLR_BK13_ESCAPE_J_FPC3 Clearance Constraint (Gap=0.13mm) (InRegionAbsolute(1732.2835,409.4488,2011.8110,594.4882) And (InComponent('J_FPC3') Or InNet('3V0_ANA') Or InNet('GND') Or InNet('NetJ_FPC3_8') Or InNet('Va_3') Or InNet('Vb_3') Or InNet('Vc_3'))),(InRegionAbsolute(1732.2835,409.4488,2011.8110,594.4882) And (InComponent('J_FPC3') Or InNet('3V0_ANA') Or InNet('GND') Or InNet('NetJ_FPC3_8') Or InNet('Va_3') Or InNet('Vb_3') Or InNet('Vc_3'))) Detected.

Error : Pad J_FPC3-6 Appears to be unroutable. Violation against Rule - CLR_BK13_ESCAPE_J_FPC3 Clearance Constraint (Gap=0.13mm) (InRegionAbsolute(1732.2835,409.4488,2011.8110,594.4882) And (InComponent('J_FPC3') Or InNet('3V0_ANA') Or InNet('GND') Or InNet('NetJ_FPC3_8') Or InNet('Va_3') Or InNet('Vb_3') Or InNet('Vc_3'))),(InRegionAbsolute(1732.2835,409.4488,2011.8110,594.4882) And (InComponent('J_FPC3') Or InNet('3V0_ANA') Or InNet('GND') Or InNet('NetJ_FPC3_8') Or InNet('Va_3') Or InNet('Vb_3') Or InNet('Vc_3'))) Detected.

Error : Pad J_FPC3-P1_2 Appears to be unroutable. Violation against Rule - CLR_BK13_ESCAPE_J_FPC3 Clearance Constraint (Gap=0.13mm) (InRegionAbsolute(1732.2835,409.4488,2011.8110,594.4882) And (InComponent('J_FPC3') Or InNet('3V0_ANA') Or InNet('GND') Or InNet('NetJ_FPC3_8') Or InNet('Va_3') Or InNet('Vb_3') Or InNet('Vc_3'))),(InRegionAbsolute(1732.2835,409.4488,2011.8110,594.4882) And (InComponent('J_FPC3') Or InNet('3V0_ANA') Or InNet('GND') Or InNet('NetJ_FPC3_8') Or InNet('Va_3') Or InNet('Vb_3') Or InNet('Vc_3'))) Detected.

Error : Pad J_FPC3-P1_1 Appears to be unroutable. Violation against Rule - CLR_BK13_ESCAPE_J_FPC3 Clearance Constraint (Gap=0.13mm) (InRegionAbsolute(1732.2835,409.4488,2011.8110,594.4882) And (InComponent('J_FPC3') Or InNet('3V0_ANA') Or InNet('GND') Or InNet('NetJ_FPC3_8') Or InNet('Va_3') Or InNet('Vb_3') Or InNet('Vc_3'))),(InRegionAbsolute(1732.2835,409.4488,2011.8110,594.4882) And (InComponent('J_FPC3') Or InNet('3V0_ANA') Or InNet('GND') Or InNet('NetJ_FPC3_8') Or InNet('Va_3') Or InNet('Vb_3') Or InNet('Vc_3'))) Detected.

Error : Pad J_FPC3-P2_1 Appears to be unroutable. Violation against Rule - CLR_BK13_ESCAPE_J_FPC3 Clearance Constraint (Gap=0.13mm) (InRegionAbsolute(1732.2835,409.4488,2011.8110,594.4882) And (InComponent('J_FPC3') Or InNet('3V0_ANA') Or InNet('GND') Or InNet('NetJ_FPC3_8') Or InNet('Va_3') Or InNet('Vb_3') Or InNet('Vc_3'))),(InRegionAbsolute(1732.2835,409.4488,2011.8110,594.4882) And (InComponent('J_FPC3') Or InNet('3V0_ANA') Or InNet('GND') Or InNet('NetJ_FPC3_8') Or InNet('Va_3') Or InNet('Vb_3') Or InNet('Vc_3'))) Detected.

Error : Pad J_FPC3-P2_2 Appears to be unroutable. Violation against Rule - CLR_BK13_ESCAPE_J_FPC3 Clearance Constraint (Gap=0.13mm) (InRegionAbsolute(1732.2835,409.4488,2011.8110,594.4882) And (InComponent('J_FPC3') Or InNet('3V0_ANA') Or InNet('GND') Or InNet('NetJ_FPC3_8') Or InNet('Va_3') Or InNet('Vb_3') Or InNet('Vc_3'))),(InRegionAbsolute(1732.2835,409.4488,2011.8110,594.4882) And (InComponent('J_FPC3') Or InNet('3V0_ANA') Or InNet('GND') Or InNet('NetJ_FPC3_8') Or InNet('Va_3') Or InNet('Vb_3') Or InNet('Vc_3'))) Detected.

Error : Pad J_FPC3-P2_3 Appears to be unroutable. Violation against Rule - CLR_BK13_ESCAPE_J_FPC3 Clearance Constraint (Gap=0.13mm) (InRegionAbsolute(1732.2835,409.4488,2011.8110,594.4882) And (InComponent('J_FPC3') Or InNet('3V0_ANA') Or InNet('GND') Or InNet('NetJ_FPC3_8') Or InNet('Va_3') Or InNet('Vb_3') Or InNet('Vc_3'))),(InRegionAbsolute(1732.2835,409.4488,2011.8110,594.4882) And (InComponent('J_FPC3') Or InNet('3V0_ANA') Or InNet('GND') Or InNet('NetJ_FPC3_8') Or InNet('Va_3') Or InNet('Vb_3') Or InNet('Vc_3'))) Detected.

Error : Pad J_FPC3-P1_3 Appears to be unroutable. Violation against Rule - CLR_BK13_ESCAPE_J_FPC3 Clearance Constraint (Gap=0.13mm) (InRegionAbsolute(1732.2835,409.4488,2011.8110,594.4882) And (InComponent('J_FPC3') Or InNet('3V0_ANA') Or InNet('GND') Or InNet('NetJ_FPC3_8') Or InNet('Va_3') Or InNet('Vb_3') Or InNet('Vc_3'))),(InRegionAbsolute(1732.2835,409.4488,2011.8110,594.4882) And (InComponent('J_FPC3') Or InNet('3V0_ANA') Or InNet('GND') Or InNet('NetJ_FPC3_8') Or InNet('Va_3') Or InNet('Vb_3') Or InNet('Vc_3'))) Detected.

Error : Pad J_FPC3-10 Appears to be unroutable. Violation against Rule - CLR_BK13_ESCAPE_J_FPC3 Clearance Constraint (Gap=0.13mm) (InRegionAbsolute(1732.2835,409.4488,2011.8110,594.4882) And (InComponent('J_FPC3') Or InNet('3V0_ANA') Or InNet('GND') Or InNet('NetJ_FPC3_8') Or InNet('Va_3') Or InNet('Vb_3') Or InNet('Vc_3'))),(InRegionAbsolute(1732.2835,409.4488,2011.8110,594.4882) And (InComponent('J_FPC3') Or InNet('3V0_ANA') Or InNet('GND') Or InNet('NetJ_FPC3_8') Or InNet('Va_3') Or InNet('Vb_3') Or InNet('Vc_3'))) Detected.

Error : Pad J_FPC2-3 Appears to be unroutable. Violation against Rule - CLR_BK13_ESCAPE_J_FPC2 Clearance Constraint (Gap=0.13mm) (InRegionAbsolute(1220.4724,409.4488,1500.0000,594.4882) And (InComponent('J_FPC2') Or InNet('3V0_ANA') Or InNet('GND') Or InNet('NetJ_FPC2_8') Or InNet('Va_2') Or InNet('Vb_2') Or InNet('Vc_2'))),(InRegionAbsolute(1220.4724,409.4488,1500.0000,594.4882) And (InComponent('J_FPC2') Or InNet('3V0_ANA') Or InNet('GND') Or InNet('NetJ_FPC2_8') Or InNet('Va_2') Or InNet('Vb_2') Or InNet('Vc_2'))) Detected.

Error : Pad J_FPC2-4 Appears to be unroutable. Violation against Rule - CLR_BK13_ESCAPE_J_FPC2 Clearance Constraint (Gap=0.13mm) (InRegionAbsolute(1220.4724,409.4488,1500.0000,594.4882) And (InComponent('J_FPC2') Or InNet('3V0_ANA') Or InNet('GND') Or InNet('NetJ_FPC2_8') Or InNet('Va_2') Or InNet('Vb_2') Or InNet('Vc_2'))),(InRegionAbsolute(1220.4724,409.4488,1500.0000,594.4882) And (InComponent('J_FPC2') Or InNet('3V0_ANA') Or InNet('GND') Or InNet('NetJ_FPC2_8') Or InNet('Va_2') Or InNet('Vb_2') Or InNet('Vc_2'))) Detected.

Error : Pad J_FPC2-5 Appears to be unroutable. Violation against Rule - CLR_BK13_ESCAPE_J_FPC2 Clearance Constraint (Gap=0.13mm) (InRegionAbsolute(1220.4724,409.4488,1500.0000,594.4882) And (InComponent('J_FPC2') Or InNet('3V0_ANA') Or InNet('GND') Or InNet('NetJ_FPC2_8') Or InNet('Va_2') Or InNet('Vb_2') Or InNet('Vc_2'))),(InRegionAbsolute(1220.4724,409.4488,1500.0000,594.4882) And (InComponent('J_FPC2') Or InNet('3V0_ANA') Or InNet('GND') Or InNet('NetJ_FPC2_8') Or InNet('Va_2') Or InNet('Vb_2') Or InNet('Vc_2'))) Detected.

Error : Pad J_FPC2-2 Appears to be unroutable. Violation against Rule - CLR_BK13_ESCAPE_J_FPC2 Clearance Constraint (Gap=0.13mm) (InRegionAbsolute(1220.4724,409.4488,1500.0000,594.4882) And (InComponent('J_FPC2') Or InNet('3V0_ANA') Or InNet('GND') Or InNet('NetJ_FPC2_8') Or InNet('Va_2') Or InNet('Vb_2') Or InNet('Vc_2'))),(InRegionAbsolute(1220.4724,409.4488,1500.0000,594.4882) And (InComponent('J_FPC2') Or InNet('3V0_ANA') Or InNet('GND') Or InNet('NetJ_FPC2_8') Or InNet('Va_2') Or InNet('Vb_2') Or InNet('Vc_2'))) Detected.

Error : Pad J_FPC2-1 Appears to be unroutable. Violation against Rule - CLR_BK13_ESCAPE_J_FPC2 Clearance Constraint (Gap=0.13mm) (InRegionAbsolute(1220.4724,409.4488,1500.0000,594.4882) And (InComponent('J_FPC2') Or InNet('3V0_ANA') Or InNet('GND') Or InNet('NetJ_FPC2_8') Or InNet('Va_2') Or InNet('Vb_2') Or InNet('Vc_2'))),(InRegionAbsolute(1220.4724,409.4488,1500.0000,594.4882) And (InComponent('J_FPC2') Or InNet('3V0_ANA') Or InNet('GND') Or InNet('NetJ_FPC2_8') Or InNet('Va_2') Or InNet('Vb_2') Or InNet('Vc_2'))) Detected.

Error : Pad J_FPC2-8 Appears to be unroutable. Violation against Rule - CLR_BK13_ESCAPE_J_FPC2 Clearance Constraint (Gap=0.13mm) (InRegionAbsolute(1220.4724,409.4488,1500.0000,594.4882) And (InComponent('J_FPC2') Or InNet('3V0_ANA') Or InNet('GND') Or InNet('NetJ_FPC2_8') Or InNet('Va_2') Or InNet('Vb_2') Or InNet('Vc_2'))),(InRegionAbsolute(1220.4724,409.4488,1500.0000,594.4882) And (InComponent('J_FPC2') Or InNet('3V0_ANA') Or InNet('GND') Or InNet('NetJ_FPC2_8') Or InNet('Va_2') Or InNet('Vb_2') Or InNet('Vc_2'))) Detected.

Error : Pad J_FPC2-9 Appears to be unroutable. Violation against Rule - CLR_BK13_ESCAPE_J_FPC2 Clearance Constraint (Gap=0.13mm) (InRegionAbsolute(1220.4724,409.4488,1500.0000,594.4882) And (InComponent('J_FPC2') Or InNet('3V0_ANA') Or InNet('GND') Or InNet('NetJ_FPC2_8') Or InNet('Va_2') Or InNet('Vb_2') Or InNet('Vc_2'))),(InRegionAbsolute(1220.4724,409.4488,1500.0000,594.4882) And (InComponent('J_FPC2') Or InNet('3V0_ANA') Or InNet('GND') Or InNet('NetJ_FPC2_8') Or InNet('Va_2') Or InNet('Vb_2') Or InNet('Vc_2'))) Detected.

Error : Pad J_FPC2-7 Appears to be unroutable. Violation against Rule - CLR_BK13_ESCAPE_J_FPC2 Clearance Constraint (Gap=0.13mm) (InRegionAbsolute(1220.4724,409.4488,1500.0000,594.4882) And (InComponent('J_FPC2') Or InNet('3V0_ANA') Or InNet('GND') Or InNet('NetJ_FPC2_8') Or InNet('Va_2') Or InNet('Vb_2') Or InNet('Vc_2'))),(InRegionAbsolute(1220.4724,409.4488,1500.0000,594.4882) And (InComponent('J_FPC2') Or InNet('3V0_ANA') Or InNet('GND') Or InNet('NetJ_FPC2_8') Or InNet('Va_2') Or InNet('Vb_2') Or InNet('Vc_2'))) Detected.

Error : Pad J_FPC2-6 Appears to be unroutable. Violation against Rule - CLR_BK13_ESCAPE_J_FPC2 Clearance Constraint (Gap=0.13mm) (InRegionAbsolute(1220.4724,409.4488,1500.0000,594.4882) And (InComponent('J_FPC2') Or InNet('3V0_ANA') Or InNet('GND') Or InNet('NetJ_FPC2_8') Or InNet('Va_2') Or InNet('Vb_2') Or InNet('Vc_2'))),(InRegionAbsolute(1220.4724,409.4488,1500.0000,594.4882) And (InComponent('J_FPC2') Or InNet('3V0_ANA') Or InNet('GND') Or InNet('NetJ_FPC2_8') Or InNet('Va_2') Or InNet('Vb_2') Or InNet('Vc_2'))) Detected.

Error : Pad J_FPC2-P1_2 Appears to be unroutable. Violation against Rule - CLR_BK13_ESCAPE_J_FPC2 Clearance Constraint (Gap=0.13mm) (InRegionAbsolute(1220.4724,409.4488,1500.0000,594.4882) And (InComponent('J_FPC2') Or InNet('3V0_ANA') Or InNet('GND') Or InNet('NetJ_FPC2_8') Or InNet('Va_2') Or InNet('Vb_2') Or InNet('Vc_2'))),(InRegionAbsolute(1220.4724,409.4488,1500.0000,594.4882) And (InComponent('J_FPC2') Or InNet('3V0_ANA') Or InNet('GND') Or InNet('NetJ_FPC2_8') Or InNet('Va_2') Or InNet('Vb_2') Or InNet('Vc_2'))) Detected.

Error : Pad J_FPC2-P1_1 Appears to be unroutable. Violation against Rule - CLR_BK13_ESCAPE_J_FPC2 Clearance Constraint (Gap=0.13mm) (InRegionAbsolute(1220.4724,409.4488,1500.0000,594.4882) And (InComponent('J_FPC2') Or InNet('3V0_ANA') Or InNet('GND') Or InNet('NetJ_FPC2_8') Or InNet('Va_2') Or InNet('Vb_2') Or InNet('Vc_2'))),(InRegionAbsolute(1220.4724,409.4488,1500.0000,594.4882) And (InComponent('J_FPC2') Or InNet('3V0_ANA') Or InNet('GND') Or InNet('NetJ_FPC2_8') Or InNet('Va_2') Or InNet('Vb_2') Or InNet('Vc_2'))) Detected.

Error : Pad J_FPC2-P2_1 Appears to be unroutable. Violation against Rule - CLR_BK13_ESCAPE_J_FPC2 Clearance Constraint (Gap=0.13mm) (InRegionAbsolute(1220.4724,409.4488,1500.0000,594.4882) And (InComponent('J_FPC2') Or InNet('3V0_ANA') Or InNet('GND') Or InNet('NetJ_FPC2_8') Or InNet('Va_2') Or InNet('Vb_2') Or InNet('Vc_2'))),(InRegionAbsolute(1220.4724,409.4488,1500.0000,594.4882) And (InComponent('J_FPC2') Or InNet('3V0_ANA') Or InNet('GND') Or InNet('NetJ_FPC2_8') Or InNet('Va_2') Or InNet('Vb_2') Or InNet('Vc_2'))) Detected.

Error : Pad J_FPC2-P2_2 Appears to be unroutable. Violation against Rule - CLR_BK13_ESCAPE_J_FPC2 Clearance Constraint (Gap=0.13mm) (InRegionAbsolute(1220.4724,409.4488,1500.0000,594.4882) And (InComponent('J_FPC2') Or InNet('3V0_ANA') Or InNet('GND') Or InNet('NetJ_FPC2_8') Or InNet('Va_2') Or InNet('Vb_2') Or InNet('Vc_2'))),(InRegionAbsolute(1220.4724,409.4488,1500.0000,594.4882) And (InComponent('J_FPC2') Or InNet('3V0_ANA') Or InNet('GND') Or InNet('NetJ_FPC2_8') Or InNet('Va_2') Or InNet('Vb_2') Or InNet('Vc_2'))) Detected.

Error : Pad J_FPC2-P2_3 Appears to be unroutable. Violation against Rule - CLR_BK13_ESCAPE_J_FPC2 Clearance Constraint (Gap=0.13mm) (InRegionAbsolute(1220.4724,409.4488,1500.0000,594.4882) And (InComponent('J_FPC2') Or InNet('3V0_ANA') Or InNet('GND') Or InNet('NetJ_FPC2_8') Or InNet('Va_2') Or InNet('Vb_2') Or InNet('Vc_2'))),(InRegionAbsolute(1220.4724,409.4488,1500.0000,594.4882) And (InComponent('J_FPC2') Or InNet('3V0_ANA') Or InNet('GND') Or InNet('NetJ_FPC2_8') Or InNet('Va_2') Or InNet('Vb_2') Or InNet('Vc_2'))) Detected.

Error : Pad J_FPC2-P1_3 Appears to be unroutable. Violation against Rule - CLR_BK13_ESCAPE_J_FPC2 Clearance Constraint (Gap=0.13mm) (InRegionAbsolute(1220.4724,409.4488,1500.0000,594.4882) And (InComponent('J_FPC2') Or InNet('3V0_ANA') Or InNet('GND') Or InNet('NetJ_FPC2_8') Or InNet('Va_2') Or InNet('Vb_2') Or InNet('Vc_2'))),(InRegionAbsolute(1220.4724,409.4488,1500.0000,594.4882) And (InComponent('J_FPC2') Or InNet('3V0_ANA') Or InNet('GND') Or InNet('NetJ_FPC2_8') Or InNet('Va_2') Or InNet('Vb_2') Or InNet('Vc_2'))) Detected.

Error : Pad J_FPC2-10 Appears to be unroutable. Violation against Rule - CLR_BK13_ESCAPE_J_FPC2 Clearance Constraint (Gap=0.13mm) (InRegionAbsolute(1220.4724,409.4488,1500.0000,594.4882) And (InComponent('J_FPC2') Or InNet('3V0_ANA') Or InNet('GND') Or InNet('NetJ_FPC2_8') Or InNet('Va_2') Or InNet('Vb_2') Or InNet('Vc_2'))),(InRegionAbsolute(1220.4724,409.4488,1500.0000,594.4882) And (InComponent('J_FPC2') Or InNet('3V0_ANA') Or InNet('GND') Or InNet('NetJ_FPC2_8') Or InNet('Va_2') Or InNet('Vb_2') Or InNet('Vc_2'))) Detected.

Error : Pad J_FPC1-3 Appears to be unroutable. Violation against Rule - CLR_BK13_ESCAPE_J_FPC1 Clearance Constraint (Gap=0.13mm) (InRegionAbsolute(708.6614,409.4488,988.1890,594.4882) And (InComponent('J_FPC1') Or InNet('3V0_ANA') Or InNet('GND') Or InNet('NetJ_FPC1_8') Or InNet('Va_1') Or InNet('Vb_1') Or InNet('Vc_1'))),(InRegionAbsolute(708.6614,409.4488,988.1890,594.4882) And (InComponent('J_FPC1') Or InNet('3V0_ANA') Or InNet('GND') Or InNet('NetJ_FPC1_8') Or InNet('Va_1') Or InNet('Vb_1') Or InNet('Vc_1'))) Detected.

Error : Pad J_FPC1-4 Appears to be unroutable. Violation against Rule - CLR_BK13_ESCAPE_J_FPC1 Clearance Constraint (Gap=0.13mm) (InRegionAbsolute(708.6614,409.4488,988.1890,594.4882) And (InComponent('J_FPC1') Or InNet('3V0_ANA') Or InNet('GND') Or InNet('NetJ_FPC1_8') Or InNet('Va_1') Or InNet('Vb_1') Or InNet('Vc_1'))),(InRegionAbsolute(708.6614,409.4488,988.1890,594.4882) And (InComponent('J_FPC1') Or InNet('3V0_ANA') Or InNet('GND') Or InNet('NetJ_FPC1_8') Or InNet('Va_1') Or InNet('Vb_1') Or InNet('Vc_1'))) Detected.

Error : Pad J_FPC1-5 Appears to be unroutable. Violation against Rule - CLR_BK13_ESCAPE_J_FPC1 Clearance Constraint (Gap=0.13mm) (InRegionAbsolute(708.6614,409.4488,988.1890,594.4882) And (InComponent('J_FPC1') Or InNet('3V0_ANA') Or InNet('GND') Or InNet('NetJ_FPC1_8') Or InNet('Va_1') Or InNet('Vb_1') Or InNet('Vc_1'))),(InRegionAbsolute(708.6614,409.4488,988.1890,594.4882) And (InComponent('J_FPC1') Or InNet('3V0_ANA') Or InNet('GND') Or InNet('NetJ_FPC1_8') Or InNet('Va_1') Or InNet('Vb_1') Or InNet('Vc_1'))) Detected.

Error : Pad J_FPC1-2 Appears to be unroutable. Violation against Rule - CLR_BK13_ESCAPE_J_FPC1 Clearance Constraint (Gap=0.13mm) (InRegionAbsolute(708.6614,409.4488,988.1890,594.4882) And (InComponent('J_FPC1') Or InNet('3V0_ANA') Or InNet('GND') Or InNet('NetJ_FPC1_8') Or InNet('Va_1') Or InNet('Vb_1') Or InNet('Vc_1'))),(InRegionAbsolute(708.6614,409.4488,988.1890,594.4882) And (InComponent('J_FPC1') Or InNet('3V0_ANA') Or InNet('GND') Or InNet('NetJ_FPC1_8') Or InNet('Va_1') Or InNet('Vb_1') Or InNet('Vc_1'))) Detected.

Error : Pad J_FPC1-1 Appears to be unroutable. Violation against Rule - CLR_BK13_ESCAPE_J_FPC1 Clearance Constraint (Gap=0.13mm) (InRegionAbsolute(708.6614,409.4488,988.1890,594.4882) And (InComponent('J_FPC1') Or InNet('3V0_ANA') Or InNet('GND') Or InNet('NetJ_FPC1_8') Or InNet('Va_1') Or InNet('Vb_1') Or InNet('Vc_1'))),(InRegionAbsolute(708.6614,409.4488,988.1890,594.4882) And (InComponent('J_FPC1') Or InNet('3V0_ANA') Or InNet('GND') Or InNet('NetJ_FPC1_8') Or InNet('Va_1') Or InNet('Vb_1') Or InNet('Vc_1'))) Detected.

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

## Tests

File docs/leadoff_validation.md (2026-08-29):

# Lead-off calibration & validation — 2026-08-29

Bench experiment on the real front end: **1 channel (PA0 = double-differential montage,
2 active electrodes + DRL reference)**, AC coupling, 8–12 s recordings per condition.
Analyzed with `scripts/analyze_capture.py` (which uses `dsp.leadoff_report`).

| Condition | RMS | pk-pk | medF | mains | centroid | Verdict |
|---|---|---|---|---|---|---|
| `all_connected` (rest) | **8.6 mV** | 143 mV | 216 | 4 % | 222 | 🟢 GOOD |
| `contraction` | **59 mV** | 1047 mV | **127** | 6 % | 145 | 🟢 GOOD |
| `no_active1` | 181 mV | 1609 mV | 183 | 30 % | 203 | 🔴 POOR |
| `no_active2` | 901 mV | 2981 mV | 100 | **85 %** | 105 | 🔴 POOR |
| `no_ref` (DRL off) | 835 mV | 2725 mV | 200 | 18 % | 226 | 🔴 POOR |

## Findings
- **Good band = rest 8.6 mV → strong contraction 59 mV RMS.** Real EMG confirmed: medF fell
  216 → **127 Hz** under contraction with only 6 % mains — the physiological signature.
- **All faults ≥ 181 mV RMS** → clean separation from good (≤ 59 mV).
- `no_active2` also floods mains (85 %); `no_ref` and `no_active1` are EMG-ish spectrally but
  20–100× too big — caught by the amplitude ceiling.

## Calibrated thresholds (`dsp.leadoff_report`)
- `rms_hi = 0.12 V` — amplitude ceiling (2× the measured contraction, well below the 181 mV fault floor)
- `mains_dom = 0.5` — mains-band power fraction → mains flood
- `emg_hi = 250 Hz` — spectral-centroid ceiling → non-physiological (floating) noise
- `rail_frac = 0.20` — fraction near 0 V/Vref → open/short
- **Result: 5/5 conditions classify correctly** (rest & contraction GOOD; all 3 electrode faults POOR).

## Notes
- `rms_hi` is **AFE-gain-dependent** — recalibrate (re-run this experiment) if the analog gain changes.
- **DD limitation:** the single PA0 channel flags *that a fault exists*, not *which* electrode. Per-electrode
  isolation needs the 3-node buffer taps / 16:1 mux — see roadmap Part 5.
- Re-analyze any recording: `python scripts/analyze_capture.py [path/to/emg_*.csv]`.

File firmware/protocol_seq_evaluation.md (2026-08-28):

# Sequence Number Width Evaluation

## Date
2026-08-27

## Context
- Protocol frame includes an 8-bit sequence number.
- Frame rate = 2 kHz (TIM2 sample clock, one frame per sample set).
- Each frame carries 8 channel codes.

## Calculation
- Sequence range: 0–255 (256 values).
- Frames per second: 2000.
- Time to wrap = 256 / 2000 = **0.128 seconds**.

## Impact
- If sequence number is used for lost-frame detection or reordering, the receiver cannot distinguish frames beyond 0.128 s.
- For real-time plotting, this is not critical; the GUI displays samples as they arrive.
- For recording or offline analysis, a repeated sequence makes it impossible to detect dropped frames over longer periods.

## Recommendation
- Upgrade protocol to **16-bit sequence number** in the next firmware/PC protocol revision.
- Alternatively, add a timestamp field (milliseconds) to each frame if higher precision is needed.
- Keep backward compatibility by adding a protocol version byte.

## Action Items
- [ ] Firmware: change `build_frame()` to include 16-bit sequence.
- [ ] PC side: update `FrameParser` to parse 16-bit sequence.
- [ ] Update round-trip test to cover wrap at 65536 frames (optional stress test).

## Status
Pending approval from Systems Architect.

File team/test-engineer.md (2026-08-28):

# Test Engineer

## Role
Validation, HIL simulation, signal quality.

## Responsibilities
- Unit tests for DSP
- Protocol round-trip tests
- Bench validation with known signals

## Connections
- Verifies work of [[dsp-engineer]], [[gui-engineer]], [[firmware-engineer]]

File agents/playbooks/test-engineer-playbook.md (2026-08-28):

# Test Engineer Playbook

## Role
Validation, HIL simulation, signal quality metrics.

## Knowledge Base
- `tests/` (to be created)
- `communication/protocol.py` (round-trip test)
- `dsp/dsp.py` (unit tests)
- `gui/emg_plotter.py` (smoke test)

## Workflow
1. **Search existing tests** with EMGify:
   - `graphify query "test"`
2. Create test plan for each module.
3. Write automated tests using pytest (or simple scripts).
4. Run tests and capture evidence.
5. Report results to Brain Agent with paths and outputs.

## Quality Gates
- All unit tests pass.
- Protocol round-trip 1000 frames without error.
- GUI launches and streams simulated data without crash.
- DSP metrics within tolerance.

## Exit State
"All acceptance criteria verified"

## Common Pitfalls
- Testing with unrealistic data
- Not isolating test dependencies
- Ignoring flaky tests

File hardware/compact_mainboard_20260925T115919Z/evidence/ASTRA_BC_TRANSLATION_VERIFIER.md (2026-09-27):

# Exact CL_4 translation verification

`work/astra_verify_routing_delta.py` now accepts explicit, repeatable
`--allow-move REF:DX_MM:DY_MM`. For BC, the allowance is `CL_4:-3.1:0`.

The verifier compares the original before and after native rows directly. It
requires exactly one component record and the same nonempty pad multiset for the
named component. Only component/pad centers and bounding-box coordinates may
translate by the specified displacement, within the existing 0.00015 mm numeric
tolerance. Net names, component and pad identities, layers, rotation, copper
dimensions, holes, shapes, and every other exported field remain exact. All other
component/pad records and fixed geometry retain their previous exact comparison.
The copper addition/deletion checks are unchanged.

`allowed_component_translations` contains each checked translation and the actual
native before/after rows. `unchanged` explicitly covers the remaining records;
`raw_native_record_changes` preserves the complete original differences, including
the authorized move. Existing input paths and SHA-256 hashes are retained. No
projected export is written or labeled as native.

Validation: `python -B -m unittest -v test_astra_verify_routing_delta` passed all
9 tests in 0.666 s. Fixtures cover the exact allowed move, rejection without an
allowance, changed pad net, other component/pad movement, wrong displacement,
rotation/size/layer changes, missing/duplicate pads, unknown/duplicate allowances,
unplanned copper changes, and preservation of CLI input bytes, paths, and hashes.

From `work/` after the native BC geometry export finishes:

```powershell
& 'C:/Users/PMLS/AppData/Local/Programs/Python/Python312/python.exe' -B astra_verify_routing_delta.py --before ../evidence/GEOMETRY_C2_6L_BB.txt --after ../evidence/GEOMETRY_C2_6L_BC.txt --adds ../evidence/ASTRA_CH4_READY_ADDS.csv --dels ../evidence/ASTRA_CH4_READY_DELS.csv --allow-move CL_4:-3.1:0 --output ../evidence/ASTRA_BC_DELTA.json
```

This is verifier preparation only. No CAD files or native processes were opened
or changed, and no actual BC verification result is claimed here. Native geometry
still omits net objects, rule definitions, stackup, via spans, and full component
body geometry; their separate checks and native DRC remain necessary.

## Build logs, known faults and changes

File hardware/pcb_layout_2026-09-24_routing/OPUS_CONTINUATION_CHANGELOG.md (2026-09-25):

# Opus continuation changelog — routing revision

Working revision: `hardware/pcb_layout_2026-09-24_routing/` (copied from the saved/reopened placement
checkpoint `hardware/pcb_layout_2026-09-23_drl/`, variant `PROTO_1_REMOTE_NTC`, DNP DRL provision kept per
user decision 24 Sep). The drl revision, the 16 Sep layout, the verified baseline and the user's electrode
boards are read-only for this work.

## 24 Sep 2026

| Time | Block | Result |
|---|---|---|
| 17:0x | Placement checkpoint closure in drl revision (Astra's guarded save/reopen script, user-approved) | `PCB_SAVE_REOPEN.txt` COMPLETE: 231 components / 808 pads / 15 free / 136 nets identical before and after |
| 17:1x | Routing revision created; start manifest `evidence/ROUTING_START_MANIFEST.csv` | copy of saved checkpoint |
| 17:2x | Read-only native probe + geometry export | 259 net/annotation tracks, 48 GND vias, 2 GND polygons (L2, L4), 570 connection lines |
| 18:41 | Unsaved GUI edit of NetINA1_7 found in routing copy; user chose **discard** | closed without save; reopened geometry identical to disk (0 diff), file hash unchanged |
| 19:25 | Batch 1: 5 BK13 socket escapes, GND fanout (126 vias), 6 fine-pitch escape rules, routing-layer rules (L2 never; L4 only for bottom-pad nets), routing-pass widths | readback PASS (+275 tracks, +126 vias, pads/components unchanged) |
| 20:17 | Batch 2: BK13 escapes v2 (0.13 mm keepout-clearance correct), U_WIFI1-32 via moved off antenna keepout | readback PASS (166 tracks replaced, 1 via moved) |
| 20:33 | Batch 3: solder-mask rule SMX_VIA_TENTED (IsVia, -0.35 mm): tents all vias (native via tenting setters proved non-persistent on a disposable copy) | DRC: 344 unrouted, 10 net antennae, 1 inherited silk-to-mask; 0 clearance/short/sliver |
| 20:40–21:27 | Situs autorouter trial (Route All, pre-routes locked) | **rejected, not saved**: 29 real track shorts (incl. 3V3_DIG–VSYS, CC1–CC2, 3V0_ANA–Vservo_4), 62 clearance, 75 unrouted, all SPI unrouted, analog detours up to 3x. Board reverted; geometry identical to batch-3 state (0 diff). Evidence: `evidence/DRC_SITUS1*.json`, `evidence/ROUTE_QUALITY_SITUS1.csv` |

## 25 Sep 2026 (resumed; this copy lives in worktree `.claude/worktrees/pcb-routing-0925`, branch `pcb-routing-0925`)

| Time | Block | Result |
|---|---|---|
| 15:0x | Revision copied into a git worktree (background-job isolation); Altium switched to the worktree project | reopened inside its project: MODIFIED=False; geometry identical to batch-3 (0 diff) |
| 15:1x–17:15 | Full-board router runs (router4, then array-A* + resume); two runs stopped by low system memory; a forked session briefly wrote the same output files and stood down | pass-1 partial plan recovered clean: 210 connections |
| 17:16 | Batch ROUTE_A: 803 tracks + 114 vias (208 connections), exact-checked (2 groups dropped), topology audit G1/R1/P2/M2 = 0 | readback PASS; DRC 136 unrouted, 0 clearance/short |
| 17:2x | router5 (component-to-component targets, scoped 0.2 mm fallback, bounded failures) prepared; resume run stopped by low memory | not written |
| 18:57 | **User switched to R2 (compact two-sided candidate); routing of this 80 x 45 board PAUSED** | see `hardware/compact_mainboard_20260925T115919Z/` |

## Method

All CAD writes go through native DelphiScript run inside the open Altium AD22 (22.5.1)
(`work/apply_ops.pas`: phase-1 validation of every op, then one transaction, GND polygon rebuild, save,
close, reopen, readback). Plans are computed offline from the native geometry export and pre-verified
against true pad copper and the saved clearance-rule priorities (`work/geom.py`, `work/build_ops.py`).
Altium DRC (`work/run_drc.pas`, batch HTML) is the authority after each block.

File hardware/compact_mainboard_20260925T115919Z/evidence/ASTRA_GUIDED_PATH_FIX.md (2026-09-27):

# Guided partial-rip corridor and seed plan inputs, 27 September 2026

The planner correction is in `work/repair.py:785-789`; its exact five-added/one-removed-line diff is retained in `ASTRA_GUIDED_PATH_FIX.patch`. `work/repair_guided_fix.py` is the identical controlled snapshot originally tested before the root agent authorized updating the runtime script. No native CAD, router process, production geometry load, design or rule edit was performed by this subtask.

## Planner correction

Previously `fixed_path_victims` saved `LAST_PATH` from the first route found with all local victim groups ripped. It then restored unrelated groups and verified a second route `r2` with only the selected victims ripped. That second route could take a different corridor, but `split_group` still received the first corridor. At `PARTIAL=0.35` or `0.5`, this could leave the verified route blocked while unnecessarily ripping copper elsewhere.

The function now converts successful `r2` into rows and track/via envelopes, assigns their union to `LAST_PATH`, and returns those same diagnostic rows. Failure or an empty already-connected result leaves `LAST_PATH=None`. Victim selection, tolerance values, raster checks, exact checks, clearance calculations, route ordering and final acceptance checks are unchanged. Full state restoration remains in the existing `finally` clause.

This fixes the corridor mismatch; it does not guarantee that a partially ripped route or all victim reconnections will succeed.

## Seed wrapper correction

`work/astra_route_seed.py:54-59` reads `EXTRA_PLANS` from the merged environment, including command-line overrides, using the same comma parsing and empty-entry filtering as `run_repair.py`. It rejects entries containing paths, drive separators or parent-directory names. The default plan list plus extras is recorded as `routed_plans` in `MANIFEST.json` and passed, in that order, to `repair.py` at line 66.

The tested concrete option is:

```text
EXTRA_PLANS=ASTRA_MCU_RX_REINFORCED_ADDS,ASTRA_UART_READY_ADDS
```

Seed copper remains part of the planning geometry; these extra plans identify existing native routed copper that repair may nominate as victims.

## Test evidence

Command from `work/`:

```powershell
& 'C:/Users/PMLS/AppData/Local/Programs/Python/Python312/python.exe' -B -m unittest -v test_repair_guided_path test_astra_route_seed_plans
```

Observed result: **exit 0; nine tests in 0.411 seconds; OK**.

The six planner tests compile only `fixed_path_victims`, `split_group` and `rows_for` from the actual runtime source. They use real Shapely envelopes and the real partial group selection with mocked routing results/snapshots; they never import the router. They cover both requested partial distances, verified track/via output, later-tolerance success, all-verification failure, exception rollback, and an already-connected verification. The fixture deliberately puts old-corridor copper at y=0, verified-corridor copper at y=2 and remote copper at y=5. Only the y=2 piece is selected after the fix.

The three seed-wrapper tests execute the wrapper inside temporary synthetic files with its routing subprocess mocked. They confirm the exact two requested extra plans are appended and recorded, command-line values override inherited values, empty comma entries are ignored, inherited extras work, and path entries are rejected before any subprocess starts.

`git diff --check` on the runtime files returned exit 0, with only Git's line-ending notice. The seed wrapper is an existing untracked file, so its focused changes are described above rather than appearing in the tracked repair diff.

SHA-256 before the planner edit: `DB5C92DAC31DF73A9D341EF0DA0F15261D916C9D5F159DBC2F4BF89DF3B3ED3A`.

SHA-256 after the edit, identical for `repair.py` and `repair_guided_fix.py`: `2438B5ACB61B796931D79166956BEB36827CBF5788345742AA468ACE17ABDC71`.

SHA-256 of the updated seed wrapper: `DC4CB8F86D028D483FF464886787542B394FE67E0359CB0907268DE339BDFF5A`.

Native build/delta/DRC acceptance remains the root agent's subsequent work. Repository graph refresh is also left to root because this subtask was restricted to lightweight planner edits and evidence.

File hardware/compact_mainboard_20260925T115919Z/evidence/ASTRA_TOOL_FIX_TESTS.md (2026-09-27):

# Repair-checker regression evidence

Changed only `work/consistent_repair.py` and added `work/test_consistent_repair.py`; no CAD change belongs to this fix.

Command, from `work/`:

```powershell
& 'C:/Users/PMLS/AppData/Local/Programs/Python/Python312/python.exe' -B -m unittest -v test_consistent_repair
```

Observed on 27 September 2026 after the final staging-path change: **8 tests passed**, 0.147 seconds. Every `build_ops.py` subprocess was mocked; fixtures contain tiny CSV row sets. No geometry engine, router or native application was launched by these tests.

Covered conditions:

- Nonzero checker exit returns failure and publishes no final output.
- Deletion mismatch returns failure even when `--drop-bad` exits zero.
- Missing checker summary cannot be mistaken for a clean check.
- Problems with no droppable groups return failure.
- A legitimate geometric drop removes the target/victim reroute, preserves its original victim copper, then requires a clean recheck before publishing.
- Exhausting the check limit returns failure without final outputs.
- A failed run does not overwrite previously existing output files.
- Extra-plan staging cannot accidentally write the final additions path when its filename lacks a `.csv` extension.

`build_ops.py --drop-bad` intentionally exits zero when it filters problematic addition groups. The fix therefore checks both the process exit code and the structured `PROBLEMS` / `DROPPED_GROUPS` output. It does not reject legitimate filtering merely because the first candidate had geometric problems.

Caller requirement: honor the nonzero exit status. Old final output files remain intact on failure and are not evidence that the new candidate passed. Gloss output still has incompatible deletion-group ownership and must not use this repair-specific helper.

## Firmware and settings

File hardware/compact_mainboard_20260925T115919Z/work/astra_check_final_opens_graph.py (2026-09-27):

"""Small read-only candidate graph check; no routing or CAD writes.

Besides normal connectivity, compare retained power-copper connectivity after
excluding tracks narrower than each original width threshold and 0.40 mm. This catches a replacement branch that
reaches its source only through a previously unrelated thin pad feed. It does
not prove effective junction width, current capacity, or complete pour geometry.
"""
import argparse
from collections import defaultdict
import hashlib
import json
import os
from pathlib import Path
import astra_verify_routing_delta as D
from shapely.strtree import STRtree

ENDPOINTS = {
    'MCU_WIFI_UART_TX': (('R_WIFI_UART_TX_LINK', '2'), ('U_MCU1', '92')),
    'WIFI_SPI_CS': (('U_WIFI1', '24'), ('R_WIFI_CS_PD', '1'), ('R_SPI_CS', '1')),
}


def partitions(entries):
    if not entries:
        return {}
    tree = STRtree([o.geom for _, o in entries])
    parent = list(range(len(entries)))
    def find(i):
        while parent[i] != i:
            parent[i] = parent[parent[i]]
            i = parent[i]
        return i
    for i, (_, o) in enumerate(entries):
        for j in tree.query(o.geom.buffer(.00015)):
            j = int(j)
            if j > i:
                q = entries[j][1]
                if o.layers & q.layers and o.geom.distance(q.geom) <= .00015:
                    parent[find(j)] = find(i)
    return {identity: find(i) for i, (identity, _) in enumerate(entries)}


def preserved(old, new, removed):
    before, after = partitions(old), partitions(new)
    connected = defaultdict(list)
    for identity, _ in old:
        if identity not in removed:
            connected[before[identity]].append(identity)
    splits = [ids for ids in connected.values() if len({after[i] for i in ids}) > 1]
    return before, after, splits


def describe(identity, objects):
    o = objects[identity]
    return {'id': identity, 'kind': o.kind, 'net': o.net, 'ref': o.comp, 'pin': o.name,
            'native_record': o.src, 'bounds': list(o.geom.bounds)}


def power_thresholds(old, widths):
    return sorted({.4} | {round(widths[i], 6) for i, o in old if o.kind == 'TRACK'})


def main():
    parser = argparse.ArgumentParser(description=__doc__)
    parser.add_argument('--before', required=True, type=Path)
    parser.add_argument('--adds', required=True, type=Path)
    parser.add_argument('--dels', required=True, type=Path)
    parser.add_argument('--output', required=True, type=Path)
    parser.add_argument('--require-net', action='append', choices=sorted(ENDPOINTS), required=True)
    args = parser.parse_args()
    os.environ['GEOM_FILE'] = str(args.before.resolve())
    import geom as G

    D.geometry(args.before)  # Require a complete native export before using G.
    adds, dels = D.plan(args.adds, True), D.plan(args.dels, False)
    nets = sorted({o['net'] for o in adds+dels} | set(args.require_net))
    objects = [(i, o) for i, o in enumerate(G.load()[0])
               if o.net in nets and o.kind not in ('HOLE', 'KEEPOUT')]
    removed = set()
    for row in dels:
        matches = []
        for identity, o in objects:
            if identity in removed or o.src is None:
                continue
            s = o.src
            if o.kind == 'TRACK' and 'INCOMP=False' in s and 'INPOLY=False' in s:
                primitive = D.primitive('TRACK', s[2], s[1], s[3:8], s)
            elif o.kind == 'VIA':
                primitive = D.primitive('VIA', s[1], '', s[2:6], s)
            else:
                continue
            if D.match_error(row, primitive, .00015) is not None:
                matches.append(identity)
        if len(matches) != 1:
            raise ValueError('Deletion has nonunique native match: ' + str(row))
        removed.add(matches[0])
    remaining = [(i, o) for i, o in objects if i not in removed]
    after = list(remaining)
    widths = {i: float(o.src[7]) for i, o in objects if o.kind == 'TRACK'}
    for i, row in enumerate(adds):
        v = row['values']
        o = (G.track(row['net'], row['layer'], [(v[0], v[1]), (v[2], v[3])], v[4])
             if row['kind'] == 'TRACK' else G.via(row['net'], *v))
        identity = 'new_' + str(i)
        after.append((identity, o))
        if row['kind'] == 'TRACK':
            widths[identity] = v[4]
    power_nets = set()
    for line in Path(G.CLASSES).read_text(encoding='utf-8', errors='replace').splitlines():
        fields = line.split('|')
        if len(fields) >= 3 and fields[0] == 'MEMBER' and fields[1] == 'EMG_POWER':
            power_nets.add(fields[2])
    lookup = dict(objects+after)
    graphs, power = {}, {}
    all_preserved = True
    for net in nets:
        old = [(i, o) for i, o in objects if o.net == net]
        new = [(i, o) for i, o in after if o.net == net]
        before_components, after_components, splits = preserved(old, new, removed)
        attached = {after_components[i] for i, o in remaining if o.net == net}
        detached = [i for i, _ in new if isinstance(i, str) and after_components[i] not in attached]
        pads = [{'ref': o.comp, 'pin': o.name, 'component_after': after_components[i]}
                for i, o in old if o.kind == 'PAD']
        row = {'before_component_count': len(set(before_components.values())),
               'after_component_count': len(set(after_components.values())),
               'all_retained_copper_connections_preserved': not splits,
               'split_retained_objects': [[describe(i, lookup) for i in group] for group in splits],
               'detached_additions': detached, 'pads': pads}
        if net in args.require_net:
            endpoint_ids = []
            for ref, pin in ENDPOINTS[net]:
                matches = [i for i, o in old if o.kind == 'PAD' and o.comp == ref and o.name == pin]
                if len(matches) != 1:
                    raise ValueError('Endpoint not unique: ' + repr((net, ref, pin)))
                endpoint_ids.extend(matches)
            row['requested_endpoints_connected_after'] = len({after_components[i] for i in endpoint_ids}) == 1
            all_preserved &= row['requested_endpoints_connected_after']
        all_preserved &= not splits and not detached
        graphs[net] = row
        if net in power_nets:
            checks = []
            source_ids=[i for i,o in old if net=='3V3_DIG' and o.kind=='PAD' and o.comp=='UP2' and o.name=='1']
            source_paths={i:{'ref':o.comp,'pin':o.name,'before_maximum_track_threshold_mm':0.0,'after_maximum_track_threshold_mm':0.0}
                          for i,o in old if o.kind=='PAD' and i not in source_ids}
            for threshold in power_thresholds(old, widths):
                wide_old = [(i, o) for i, o in old if o.kind != 'TRACK' or widths[i] >= threshold-.00015]
                wide_new = [(i, o) for i, o in new if o.kind != 'TRACK' or widths[i] >= threshold-.00015]
                before_wide, after_wide, power_splits = preserved(wide_old, wide_new, removed)
                if len(source_ids)==1:
                    source=source_ids[0]
                    for identity,r in source_paths.items():
                        if before_wide[identity]==before_wide[source]: r['before_maximum_track_threshold_mm']=threshold
                        if after_wide[identity]==after_wide[source]: r['after_maximum_track_threshold_mm']=threshold
                fragments=[]
                for group in power_splits:
                    pieces=defaultdict(list)
                    for identity in group: pieces[after_wide[identity]].append(identity)
                    fragments.append([{'retained_object_count':len(ids),
                                       'pads':[describe(i,lookup) for i in ids if lookup[i].kind=='PAD'],
                                       'vias':[describe(i,lookup) for i in ids if lookup[i].kind=='VIA'],
                                       'tracks':[describe(i,lookup) for i in ids if lookup[i].kind=='TRACK']}
                                      for ids in pieces.values()])
                checks.append({'minimum_track_width_mm':threshold, 'retained_connectivity_preserved':not power_splits,
                               'split_retained_objects':[[describe(i,lookup) for i in group] for group in power_splits],
                               'after_fragments':fragments})
            power[net] = {
                'retained_connectivity_at_original_width_thresholds_preserved':all(r['retained_connectivity_preserved'] for r in checks),
                'threshold_checks':checks,
                'source_pad': 'UP2.1' if len(source_ids)==1 else None,
                'source_to_pad_thresholds':list(source_paths.values()) if len(source_ids)==1 else [],
                'regressed_source_to_pad_thresholds':[r for r in source_paths.values()
                    if len(source_ids)==1 and r['after_maximum_track_threshold_mm']<r['before_maximum_track_threshold_mm']-.00015],
                'new_sub040_tracks': [r for r in adds if r['net'] == net and r['kind'] == 'TRACK' and r['values'][4] < .4-.00015],
            }
            all_preserved &= power[net]['retained_connectivity_at_original_width_thresholds_preserved']
    report = {'passed': bool(all_preserved), 'requested_nets': args.require_net,
              'graphs': graphs, 'power_width_path_preservation': power,
              'deletions_matched': len(removed), 'additions': len(adds),
              'inputs': [{'path': str(p.resolve()), 'sha256': hashlib.sha256(p.read_bytes()).hexdigest()}
                         for p in (args.before, args.adds, args.dels)],
              'limits': ['No router/native operation; affected-net copper graphs only.',
                         'Exported copper shapes use 0.00015 mm contact tolerance; pour geometry is incomplete.',
                         'Power threshold comparison detects newly required thin tracks, not effective junction widths or current capacity.',
                         'Native exact geometry, DRC and protected structure checks remain required.']}
    args.output.write_text(json.dumps(report, indent=2)+'\n', encoding='utf-8')
    print(json.dumps({'passed': report['passed'], 'additions': len(adds), 'deletions': len(removed),
                      'graphs': {n: {k: v for k, v in r.items() if k not in ('pads','split_retained_objects')} for n, r in graphs.items()},
                      'power_width_path_preservation': {n:{'passed':r['retained_connectivity_at_original_width_thresholds_preserved'],
                          'thresholds':[{'minimum_track_width_mm':t['minimum_track_width_mm'],
                                         'passed':t['retained_connectivity_preserved'],
                                         'split_group_count':len(t['split_retained_objects'])} for t in r['threshold_checks']],
                          'new_sub040_track_count':len(r['new_sub040_tracks'])} for n,r in power.items()},
                      'output': str(args.output)}, indent=2))
    return 0 if report['passed'] else 1


if __name__ == '__main__':
    raise SystemExit(main())

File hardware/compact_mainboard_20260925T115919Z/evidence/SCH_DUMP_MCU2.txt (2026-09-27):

ENTER 9/27/2026 4:28:34 PM
SCH_OPEN|MODIFIED=False
COMP|U_MCU1|EMG_R5_U_MCU1|X=2900|Y=5100
PIN|1|PE2|X=3100|Y=5100|LEN=200|ORIENT=2|HIDDEN=False
PIN|2|PE3|X=3100|Y=5000|LEN=200|ORIENT=2|HIDDEN=False
PIN|3|PE4|X=3100|Y=4900|LEN=200|ORIENT=2|HIDDEN=False
PIN|4|PE5|X=3100|Y=4800|LEN=200|ORIENT=2|HIDDEN=False
PIN|5|PE6|X=3100|Y=4700|LEN=200|ORIENT=2|HIDDEN=False
PIN|6|VBAT|X=3100|Y=4600|LEN=200|ORIENT=2|HIDDEN=False
PIN|7|PC13|X=3100|Y=4500|LEN=200|ORIENT=2|HIDDEN=False
PIN|8|PC14-OSC32_IN|X=3100|Y=4400|LEN=200|ORIENT=2|HIDDEN=False
PIN|9|PC15-OSC32_OUT|X=3100|Y=4300|LEN=200|ORIENT=2|HIDDEN=False
PIN|10|VSS_1|X=3100|Y=4200|LEN=200|ORIENT=2|HIDDEN=False
PIN|11|VDD_1|X=3100|Y=4100|LEN=200|ORIENT=2|HIDDEN=False
PIN|12|PH0-OSC_IN|X=3100|Y=4000|LEN=200|ORIENT=2|HIDDEN=False
PIN|13|PH1-OSC_OUT|X=3100|Y=3900|LEN=200|ORIENT=2|HIDDEN=False
PIN|14|NRST|X=3100|Y=3800|LEN=200|ORIENT=2|HIDDEN=False
PIN|15|PC0|X=3100|Y=3700|LEN=200|ORIENT=2|HIDDEN=False
PIN|16|PC1|X=3100|Y=3600|LEN=200|ORIENT=2|HIDDEN=False
PIN|17|PC2|X=3100|Y=3500|LEN=200|ORIENT=2|HIDDEN=False
PIN|18|PC3|X=3100|Y=3400|LEN=200|ORIENT=2|HIDDEN=False
PIN|19|VSSA|X=3100|Y=3300|LEN=200|ORIENT=2|HIDDEN=False
PIN|20|VREF-|X=3100|Y=3200|LEN=200|ORIENT=2|HIDDEN=False
PIN|21|VREF+|X=3100|Y=3100|LEN=200|ORIENT=2|HIDDEN=False
PIN|22|VDDA|X=3100|Y=3000|LEN=200|ORIENT=2|HIDDEN=False
PIN|23|PA0|X=3100|Y=2900|LEN=200|ORIENT=2|HIDDEN=False
PIN|24|PA1|X=3100|Y=2800|LEN=200|ORIENT=2|HIDDEN=False
PIN|25|PA2|X=3100|Y=2700|LEN=200|ORIENT=2|HIDDEN=False
PIN|26|PA3|X=3200|Y=2200|LEN=200|ORIENT=3|HIDDEN=False
PIN|27|VSS_2|X=3300|Y=2200|LEN=200|ORIENT=3|HIDDEN=False
PIN|28|VDD_2|X=3400|Y=2200|LEN=200|ORIENT=3|HIDDEN=False
PIN|29|PA4|X=3500|Y=2200|LEN=200|ORIENT=3|HIDDEN=False
PIN|30|PA5|X=3600|Y=2200|LEN=200|ORIENT=3|HIDDEN=False
PIN|31|PA6|X=3700|Y=2200|LEN=200|ORIENT=3|HIDDEN=False
PIN|32|PA7|X=3800|Y=2200|LEN=200|ORIENT=3|HIDDEN=False
PIN|33|PC4|X=3900|Y=2200|LEN=200|ORIENT=3|HIDDEN=False
PIN|34|PC5|X=4000|Y=2200|LEN=200|ORIENT=3|HIDDEN=False
PIN|35|PB0|X=4100|Y=2200|LEN=200|ORIENT=3|HIDDEN=False
PIN|36|PB1|X=4200|Y=2200|LEN=200|ORIENT=3|HIDDEN=False
PIN|37|PB2|X=4300|Y=2200|LEN=200|ORIENT=3|HIDDEN=False
PIN|38|PE7|X=4400|Y=2200|LEN=200|ORIENT=3|HIDDEN=False
PIN|39|PE8|X=4500|Y=2200|LEN=200|ORIENT=3|HIDDEN=False
PIN|40|PE9|X=4600|Y=2200|LEN=200|ORIENT=3|HIDDEN=False
PIN|41|PE10|X=4700|Y=2200|LEN=200|ORIENT=3|HIDDEN=False
PIN|42|PE11|X=4800|Y=2200|LEN=200|ORIENT=3|HIDDEN=False
PIN|43|PE12|X=4900|Y=2200|LEN=200|ORIENT=3|HIDDEN=False
PIN|44|PE13|X=5000|Y=2200|LEN=200|ORIENT=3|HIDDEN=False
PIN|45|PE14|X=5100|Y=2200|LEN=200|ORIENT=3|HIDDEN=False
PIN|46|PE15|X=5200|Y=2200|LEN=200|ORIENT=3|HIDDEN=False
PIN|47|PB10|X=5300|Y=2200|LEN=200|ORIENT=3|HIDDEN=False
PIN|48|VCAP|X=5400|Y=2200|LEN=200|ORIENT=3|HIDDEN=False
PIN|49|VSS_3|X=5500|Y=2200|LEN=200|ORIENT=3|HIDDEN=False
PIN|50|VDD_3|X=5600|Y=2200|LEN=200|ORIENT=3|HIDDEN=False
PIN|75|VDD_4|X=5700|Y=5100|LEN=200|ORIENT=0|HIDDEN=False
PIN|74|VSS_4|X=5700|Y=5000|LEN=200|ORIENT=0|HIDDEN=False
PIN|73|VDDUSB|X=5700|Y=4900|LEN=200|ORIENT=0|HIDDEN=False
PIN|72|PA13|X=5700|Y=4800|LEN=200|ORIENT=0|HIDDEN=False
PIN|71|PA12|X=5700|Y=4700|LEN=200|ORIENT=0|HIDDEN=False
PIN|70|PA11|X=5700|Y=4600|LEN=200|ORIENT=0|HIDDEN=False
PIN|69|PA10|X=5700|Y=4500|LEN=200|ORIENT=0|HIDDEN=False
PIN|68|PA9|X=5700|Y=4400|LEN=200|ORIENT=0|HIDDEN=False
PIN|67|PA8|X=5700|Y=4300|LEN=200|ORIENT=0|HIDDEN=False
PIN|66|PC9|X=5700|Y=4200|LEN=200|ORIENT=0|HIDDEN=False
PIN|65|PC8|X=5700|Y=4100|LEN=200|ORIENT=0|HIDDEN=False
PIN|64|PC7|X=5700|Y=4000|LEN=200|ORIENT=0|HIDDEN=False
PIN|63|PC6|X=5700|Y=3900|LEN=200|ORIENT=0|HIDDEN=False
PIN|62|PD15|X=5700|Y=3800|LEN=200|ORIENT=0|HIDDEN=False
PIN|61|PD14|X=5700|Y=3700|LEN=200|ORIENT=0|HIDDEN=False
PIN|60|PD13|X=5700|Y=3600|LEN=200|ORIENT=0|HIDDEN=False
PIN|59|PD12|X=5700|Y=3500|LEN=200|ORIENT=0|HIDDEN=False
PIN|58|PD11|X=5700|Y=3400|LEN=200|ORIENT=0|HIDDEN=False
PIN|57|PD10|X=5700|Y=3300|LEN=200|ORIENT=0|HIDDEN=False
PIN|56|PD9|X=5700|Y=3200|LEN=200|ORIENT=0|HIDDEN=False
PIN|55|PD8|X=5700|Y=3100|LEN=200|ORIENT=0|HIDDEN=False
PIN|54|PB15|X=5700|Y=3000|LEN=200|ORIENT=0|HIDDEN=False
PIN|53|PB14|X=5700|Y=2900|LEN=200|ORIENT=0|HIDDEN=False
PIN|52|PB13|X=5700|Y=2800|LEN=200|ORIENT=0|HIDDEN=False
PIN|51|PB12|X=5700|Y=2700|LEN=200|ORIENT=0|HIDDEN=False
PIN|100|VDD_5|X=3200|Y=5800|LEN=200|ORIENT=1|HIDDEN=False
PIN|99|VSS_5|X=3300|Y=5800|LEN=200|ORIENT=1|HIDDEN=False
PIN|98|PE1|X=3400|Y=5800|LEN=200|ORIENT=1|HIDDEN=False
PIN|97|PE0|X=3500|Y=5800|LEN=200|ORIENT=1|HIDDEN=False
PIN|96|PB9|X=3600|Y=5800|LEN=200|ORIENT=1|HIDDEN=False
PIN|95|PB8|X=3700|Y=5800|LEN=200|ORIENT=1|HIDDEN=False
PIN|94|PH3-BOOT0|X=3800|Y=5800|LEN=200|ORIENT=1|HIDDEN=False
PIN|93|PB7|X=3900|Y=5800|LEN=200|ORIENT=1|HIDDEN=False
PIN|92|PB6|X=4000|Y=5800|LEN=200|ORIENT=1|HIDDEN=False
PIN|91|PB5|X=4100|Y=5800|LEN=200|ORIENT=1|HIDDEN=False
PIN|90|PB4|X=4200|Y=5800|LEN=200|ORIENT=1|HIDDEN=False
PIN|89|PB3|X=4300|Y=5800|LEN=200|ORIENT=1|HIDDEN=False
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

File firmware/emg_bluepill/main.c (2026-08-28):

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
/* Includes ------------------------------------------------------------------*/
#include "main.h"

/* USER CODE BEGIN PD */
#define NCH        5
#define BLOCK      10
#define SYNC1      0xAA
#define SYNC2      0x55
#define FRAME_LEN  (5 + 2*NCH)
/* USER CODE END PD */

ADC_HandleTypeDef hadc1;
DMA_HandleTypeDef hdma_adc1;

TIM_HandleTypeDef htim3;

UART_HandleTypeDef huart1;
DMA_HandleTypeDef hdma_usart1_tx;

/* USER CODE BEGIN PV */
static volatile uint16_t adc_buf[2 * BLOCK * NCH];
static uint8_t  txbuf[2][BLOCK * FRAME_LEN];
static volatile uint8_t tx_sel = 0;
static uint8_t  seq = 0;
static volatile uint32_t tx_drops = 0;
/* USER CODE END PV */

void SystemClock_Config(void);
static void MX_GPIO_Init(void);
static void MX_DMA_Init(void);
static void MX_USART1_UART_Init(void);
static void MX_ADC1_Init(void);
static void MX_TIM3_Init(void);
/* USER CODE BEGIN 0 */
static uint16_t crc16_ccitt(const uint8_t *d, uint32_t n) {
    uint16_t crc = 0xFFFF;
    for (uint32_t i = 0; i < n; i++) {
        crc ^= (uint16_t)d[i] << 8;
        for (int b = 0; b < 8; b++)
            crc = (crc & 0x8000) ? (uint16_t)((crc << 1) ^ 0x1021)
                                 : (uint16_t)(crc << 1);
    }
    return crc;
}

static uint32_t build_frame(uint8_t *out, uint8_t s, const volatile uint16_t *codes) {
    uint8_t body[1 + 2*NCH];
    body[0] = s;
    for (int c = 0; c < NCH; c++) {
        uint16_t v = codes[c];
        body[1 + 2*c]     = (uint8_t)(v & 0xFF);
        body[1 + 2*c + 1] = (uint8_t)((v >> 8) & 0xFF);
    }
    uint16_t crc = crc16_ccitt(body, sizeof(body));
    out[0] = SYNC1; out[1] = SYNC2;
    for (uint32_t i = 0; i < sizeof(body); i++) out[2 + i] = body[i];
    out[2 + sizeof(body)]     = (uint8_t)(crc & 0xFF);
    out[2 + sizeof(body) + 1] = (uint8_t)((crc >> 8) & 0xFF);
    return FRAME_LEN;
}

static void send_half(int half) {
    const volatile uint16_t *src = &adc_buf[half * BLOCK * NCH];
    uint8_t *tx = txbuf[tx_sel];
    uint32_t off = 0;
    for (int s = 0; s < BLOCK; s++)
        off += build_frame(tx + off, seq++, &src[s * NCH]);
    if (HAL_UART_Transmit_DMA(&huart1, tx, off) != HAL_OK)
        tx_drops += BLOCK;
    else
        tx_sel ^= 1;
}
/* USER CODE END 0 */

/**
  * @brief  The application entry point.
  * @retval int
  */
int main(void)
{

  /* MCU Configuration--------------------------------------------------------*/

  /* Reset of all peripherals, Initializes the Flash interface and the Systick. */
  HAL_Init();

  /* Configure the system clock */
  SystemClock_Config();

  /* Initialize all configured peripherals */
  MX_GPIO_Init();
  MX_DMA_Init();
  MX_USART1_UART_Init();
  MX_ADC1_Init();
  MX_TIM3_Init();
  /* USER CODE BEGIN 2 */
  HAL_ADC_Start_DMA(&hadc1, (uint32_t*)adc_buf, 2 * BLOCK * NCH);
  HAL_TIM_Base_Start(&htim3);   /* If you meant TIM3, change to &htim3 */
  /* USER CODE END 2 */

  /* Infinite loop */
  /* USER CODE BEGIN WHILE */
  while (1)
    {
    /* USER CODE END WHILE */

    /* USER CODE BEGIN 3 */
    }
  /* USER CODE END 3 */
}

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
/* USER CODE BEGIN 4 */
void HAL_ADC_ConvHalfCpltCallback(ADC_HandleTypeDef *hadc)
{
  if (hadc->Instance == ADC1) send_half(0);
}

void HAL_ADC_ConvCpltCallback(ADC_HandleTypeDef *hadc)
{
  if (hadc->Instance == ADC1) send_half(1);
}
/* USER CODE END 4 */
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


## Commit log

2026-08-28 EMG-SAW: 5-channel sEMG acquisition system + real-time GUI (SAW handoff)
    Open, low-cost alternative to Noraxon MR / Delsys Trigno, built and run as a SAFe
    Agentic Workflow. Includes STM32F103 CP4 firmware (TIM3 + ADC circular-DMA ping-pong,
    2 kHz binary UART), PyQt5/pyqtgraph real-time scope (sweep/scroll, MVC%, median-freq,
    onset, live FFT, HTML reports), DSP library, 6-agent SAW harness, code knowledge-graph,
    and agent world-map. New here? Read HANDOFF.md.
    [emg_20260826_204729.csv, emg_20260826_204739.csv]
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2026-08-28 feat(phase-a): lead-off polish — quality score, hysteresis, DC-drift [dsp->gui]
    - dsp.leadoff_report(): (state, quality 0-100, metrics{rail,mains,dc}); leadoff_status
    kept as a thin wrapper (existing tests unchanged).
    - dsp.LeadoffTracker: per-channel temporal hysteresis (a new state must persist 'hold'
    ticks to latch -> no flicker) + EMA-smoothed quality.
    - ChannelPanel.set_status(state, quality): dot + tooltip shows quality %.
    - emg_plotter: use the tracker; DRL makes the mains cue cleaner (connected -> mains cancelled).
    pytest: 13 passed (quality ordering + hysteresis + live 5-lane smoke).
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2026-08-28 docs(plan): consolidate the current project plan — status, M1-M7 ladder, NOW/NEXT/LATER, ownership, gates
    Replaces the stale pre-CP6 plan with the current authoritative execution plan aligned to
    the competitive roadmap: CP6 (M2) finish, channel-1 lead-off, M3 analytics parity, then
    ADS1299 / wireless / isolation / validation. Owners routed per AGENT_OWNERSHIP.yml.
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2026-08-29 fix(leadoff): add spectral-shape cue so floating high-freq noise reads 'poor' not 'good'
    Real case (Daniyal's bench): an open PA0 showed RMS 58 mV, medF ~399 Hz -> not railed and
    not mains-dominated, so the v1 rail+mains logic wrongly read GREEN. Add a spectral-centroid
    cue: real sEMG sits ~50-150 Hz, so big amplitude with centroid > emg_hi (250 Hz default) =
    non-physiological -> 'poor'. Also penalizes the quality score. New test + EMG-realistic band
    in the good-signal test. Absolute amplitude threshold still to be calibrated on a real electrode.
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2026-08-29 fix(leadoff): calibrate amplitude ceiling from real electrode data — 5/5 conditions correct
    Bench experiment (PA0 DD montage): rest 8.6 mV, contraction 59 mV (medF 216->127 = real EMG),
    faults 181/835/901 mV. Add rms_hi=0.12 V ceiling (2x contraction, < 181 mV fault floor). Now:
    - rest & contraction -> GOOD; no_active1 / no_active2 / no_ref -> POOR (was: 2 faults missed).
    - 2 new tests (contraction stays good, amplitude blow-up -> poor). 10 leadoff tests pass.
    - docs/leadoff_validation.md records the dataset + calibrated thresholds (rms_hi gain-dependent).
2026-08-31 fix(mvc)+feat(exo): wire Set MVC button + build emg_features.py (%MVC exo/no-exo comparison)
    - MVC: the refactor left ChannelPanel's Set MVC / Clear buttons UNCONNECTED (clicking did
    nothing). Wire them in EmgScope; capture MVCref as the peak of the 100 ms moving-RMS
    (robust to click timing); footer shows the captured value. Regression test in the GUI smoke.
    - emg_features.py: from recorded CSVs (Trial-labelled mvc / noexo / exo), compute per-trial
    mean %MVC, peak %MVC, iEMG (%MVCs), % time >20% MVC, median freq, fatigue slope; then the
    No-Exo vs Exo mean+/-SD + reduction% — the 'exoskeleton helps' summary. Reuses dsp.
    - Smoke-validated: synthetic exo halves %MVC/iEMG and zeroes fa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
2026-09-01 feat(mvc): Noraxon-style MVC calibration dialog + consistent %MVC (fixes >100% confusion)
    - gui/mvc_dialog.py (new): Set MVC opens a calibration dialog = Preview-MVC + Make-MVC in one.
    Live RMS-envelope plot, Record/Stop, auto-highlights the MVC window (green LinearRegion), shows
    MVCref value + bar; Use/Redo/Cancel. MVC rule = Peak (Noraxon, default) or Best-1s (research);
    RMS window 100/250/500 ms. Fed live absolute-volts by EmgScope._update (one reader on the source).
    - emg_plotter: _set_mvc opens the dialog; live %MVC now uses the SAME RMS-envelope measure
    (current envelope / MVCref) instead of window-mean RMS -> consistent; the metric mismatch was
    the real cause of the >100% we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
2026-09-01 feat(mvc-ux Img7): EMG Baseline Check button on the scope
    Task 7/15 (Noraxon Img7). A scope 'EMG Baseline' button samples the resting signal (~2 s from
    the ring buffer) and reports per-channel RMS + pass/fail ('relaxed ✓' vs 'noisy ⚠ relax/check
    electrode + DRL') in the hint line — the pre-recording baseline check the user asked for
    (previously only a chip inside the MVC dialog). Smoke test clicks it. pytest green.
2026-09-01 fix(leadoff+mvc): quiet connected baseline reads green; colored EMG Baseline result
    Lead-off no longer flags a low-amplitude (quiet, connected) electrode as
    'poor' just because the resting spectrum is mains/noise shaped: the spectral
    cues now only apply above a quiet floor (rms>20mV). All 5 bench faults still
    POOR; rest+contraction still GOOD. EMG Baseline result now bold green/amber
    in the hint line so it's visible.
    Claude-Session: https://claude.ai/code/session_01G9sj4afWoT5mogswuyAUjA
    [emg_20260829_130504.csv, emg_20260829_130551.csv, emg_20260829_130638.csv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]
2026-09-01 fix(leadoff): detect disconnected lead by 200/400 Hz signature; safe result banner
    Empirical AFE finding (Daniyal): a *connected* signal lead shows mains pickup
    at 50/100 Hz; when it comes OFF the pickup vanishes and sharp lines appear at
    4x/8x mains (200/400 Hz) at LOW amplitude -- which the RMS/quiet-floor test
    alone reads green. Added an amplitude-independent lead-off cue: power at
    200+400 Hz > 1.5x power at 50+100 Hz and > 20% of total -> 'open'. Verified
    against all bench + today's captures (real contractions stay GOOD, faults
    OPEN/POOR); hh% surfaced in analyze_capture. Baseline result now shown in a
    big in-window banner instead of a top-level QMessageBox (the retained dialog
    segfaulte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
2026-09-02 feat(scope): % MVC target guide line + band (hold-a-target fatigue biofeedback)
    New 'Target' checkbox + % spinbox on the toolbar: in the % MVC view it draws a
    dashed green target line at the chosen % with a +/-5% tolerance band per lane, so
    the user can hold a constant effort against real resistance -> proper constant-
    force fatigue (RMS steady/up while medF falls = textbook curve). Shows only in
    % MVC view; tracks view-state changes. +smoke assertion. Also adds analyze_graded.py
    (campaign %MVC-per-segment helper).
    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
    [emg_20260902_161344_S01_rest_2026-09-02_16_13.csv, emg_20260902_163300_S01_mvc_Subject_S01_2026-09-02_16_33.csv, emg_20260902_164011_S01_graded_2026-09-02_16_4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]
2026-09-02 fix(scope): two-row toolbar so nothing clips; live status + actions always visible
    The single-row toolbar (~24 widgets) overflowed and truncated on resize -- Pause,
    Record and the live S/s/drop/crc/fat readout were cut off. Split into two rows:
    row1 = scope/signal controls + the live status (right); row2 = view/processing
    toggles + Amp-Smooth/Processing/Baseline/Spectrum + Pause/Record (right). Shrank
    the Notes box (max 280px) so the session-bar buttons stay put. Build + 48 tests green.
    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
    [emg_20260902_191800_S01_fatigue_2026-09-02_19_19.csv]
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2026-09-26 feat(hardware): C2 routing trial round 1 - 206/283 signal connections, DRC clean
    Native AD22 routing trial on candidate C2 (59.1 x 36 mm), 4 layers:
    - Converter hot loop restored from B's designed copper (16 tracks + 2
    cap GND vias, mirrored with the flipped cell onto Bottom); native DRC
    clean under the re-anchored CLR_FINAL exceptions.
    - Six CLR_FINE_ESCAPE rules re-anchored to C2 part positions.
    - Routability tweaks: DNP DRL input resistors upright (DRL_SUM pads in
    one row), TP_WIFI_CHIP_EN moved clear of C_WIFI_EN.
    - Router (router5, cropped grid) pass 1 routed 243/283; exact check
    (build_ops --drop-bad) kept 205 connections; topology audit: 0 tracks
    on L2, 0 copper in the anten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
    [EMG_MainBoard_Layout.PcbDoc, PLAN_C2_COMPONENTS.csv, ROUTE_PARTIAL_C2TRIAL_p1.csv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]
2026-09-26 feat(hardware): C2 routing trial round 2 - 241/283 routed, G2 fails on 4 layers
    Round 2 of the native AD22 routing trial on candidate C2 (59.1 x 36 mm):
    - Router pass 1 routed 48/77 remaining trial connections; exact check
    kept 35 (dropped Vc_1..5 at 0.19 mm to BK13 keep-outs, VOUT_3/5 at
    0.227 mm to RG pads, 4 vias on pads, one MISO/UART_TX crossing).
    - Topology audit: 0 tracks on L2, 0 copper in the antenna zone, 0 vias
    on the switch node / VCAP.
    - Written natively (+176 tracks, +37 vias; 939 / 173 after save+reopen).
    - Altium DRC: 0 short / clearance / width / component / antenna;
    302 unrouted = 260 excluded (GND, supplies, BK13 escapes) + 42 trial
    signals. Trial total 241/283 =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
    [EMG_MainBoard_Layout.PcbDoc, ROUTE_PARTIAL_C2R2_p1.csv, ROUTE_PARTIAL_C2R2_p2.csv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]
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2026-09-26 feat(hardware): C2 6L routing rounds 1-2 - DRL provisions moved out of BK13 keep-outs, 96 unrouted left
    - Altium probe (DRC_KEEPOUT_PROBE): the J_FPCn footprint keep-out blocks tracks
    and vias on every layer, so pad 1 of the DNP DRL input resistors placed under
    the sockets could never be connected. relocate_drl.py re-placed the 15
    R_DRL_VAn/VBn/VCn on the Bottom in the gap right of each socket (0.2 mm body
    gap, native component clearance clean); nets and BOM unchanged.
    - Router rounds 1-2 on 6 layers (L1/L3/L5/L6 routable, L5 analog pour reserved)
    + stitch retry: 101 more connections written (batch B, C), dangling copper
    pruned from Altium's antenna list.
    - Altium DRC (state F):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
    [BATCH_C_OK.csv, EMG_MainBoard_Layout.PcbDoc, RIP_FOR_DRL_MOVE.csv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]
2026-09-26 feat(hardware): C2 6L routing rounds 3-7 - 61 unrouted, Vservo cross-side links solved
    - Router: 6L retarget + MCU fan-out reservation (LQFP interior on L1 only for
    MCU-pin nets), via-in-pad (POFV) option, no relaxed-clearance attempts, via
    0.1 mm from pads, FIRST / FIRST_NETS / SHUFFLE ordering, big last-resort window.
    - Rip-up tools: rip_blockers.py (endpoint blockers), rip_region.py (region rip,
    whole connections only, fixed copper protected), apply_rip_offline.py,
    diag_route.py (per-connection blockage diagnosis).
    - Top-layer through-traffic under the STM32 (VSYS trunk, Q_SHDN, C2_EN1)
    ripped and re-routed on inner layers.
    - Channels 2-5: routed copper in the INA cores ripped a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
    [EMG_MainBoard_Layout.PcbDoc, RIP_BLOCKERS_G.csv, RIP_BLOCKERS_G2.csv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]
2026-09-26 feat(hardware): C2 6L - L5 GND fill + L1 Top GND pour, local repair loop; 57 unrouted
    - Pours: EMG_L5_GND_FILL (L5 outside the 3V0_ANA plane, 0.3 mm gap) and
    EMG_L1_TOP_GND (Top), both valid; closed 2 GND links.
    - Global re-route experiment on a throwaway copy (all routed copper ripped,
    395 connections, two orders): 57 / 64 left -> not better than the board,
    not applied.
    - repair.py: corridor rip-up-and-repair loop with strict acceptance;
    exact-checked result written (59 tracks, 4 vias added, 47 objects removed).
    - Altium DRC (state O): 0 short / clearance / width / component;
    57 unrouted (10 GND, 6 3V0_ANA, 5 3V3_DIG, 36 signals), 1 antenna.
    Remaining links sit in three placemen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
    [EMG_MainBoard_Layout.PcbDoc, REPAIR_ADDS_N.csv, REPAIR_ADDS_N2.csv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]
2026-09-26 feat(hardware): C2 6L - charger placement nudges + MCU-edge re-route; 51 unrouted
    User decision (26 Sep 21:52): keep the rules, nudge parts.
    - Charger (UP1, Bottom, under USB-C) pin escapes opened by small moves
    (legal by native DRC: 0 component clearance):
    C_BAT x -0.30 mm -> EN1_BIAS and PGOOD escape between its pads
    R_TS_TOP x -0.40 mm -> VBAT lane from UP1 pins 2/3
    C_IN_ (14.35,36.40) -> (14.85,36.75) -> TMR escape to R_TMR
    R_PGOOD (11.45,42.30) -> (17.60,42.35) (pull-up moved along its net)
    Nets and BOM unchanged.
    - Charger box ripped and re-routed charger-pins-first (36 connections);
    MCU top/right-edge region re-route (+2).
    - Tools: place_part.py (le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
    [DEL_BATCH_P.csv, EMG_MainBoard_Layout.PcbDoc, REG_CHG_ADDS.csv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]
2026-09-26 feat(hardware): C2 6L - analog repair loop + stitch retry; 44 unrouted
    - repair.py over all links (region attempts in the analog band were rolled
    back: the band trades links 1:1 at 0.25 mm - via sites next to pads are the
    limit, L3/L5 have spare capacity); corridor repairs gained 12, 10 kept after
    consistent_repair.py (dropped repairs restore their victims).
    - 3 more plane stitches.
    - Altium DRC (state R): 0 short / clearance / width / component;
    44 unrouted (7 GND, 5 3V0_ANA, 4 3V3_DIG, 28 signals), 5 antennae.
    Claude-Session: https://claude.ai/code/session_01Qvsr6zsjPV9z83rCjUCGhE
    [EMG_MainBoard_Layout.PcbDoc, REG_ANA_ADDS.csv, REG_ANA_ADDS_OK.csv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]
2026-09-26 feat(hardware): C2 6L - exact-validated repair loop; 42 unrouted
    - repair.py now runs the build_ops exact check (clearance by class, holes,
    edge, keep-outs, L5 reservation, via-on-pad / VIP) inside the loop before
    accepting any change -> 0 groups dropped at write time.
    - consistent_repair.py for write-safe merging; 8 connections gained offline.
    - Altium DRC (state T): 0 short / clearance / width / component;
    42 unrouted (7 GND, 4 3V3_DIG, 2 3V0_ANA, 29 signals), 1 antenna.
    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
    [EMG_MainBoard_Layout.PcbDoc, PRUNE_R.csv, PRUNE_S.csv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]
2026-09-26 feat(hardware): C2 6L - branch-complete repair reconnects; 38 unrouted
    - repair.py re-routes ripped connections at every touch point (branched
    groups no longer leave a stub behind).
    - Altium DRC (state U): 0 short / clearance / width / component / antenna;
    38 unrouted (7 GND, 4 3V3_DIG, 2 3V0_ANA, 25 signals).
    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
    [EMG_MainBoard_Layout.PcbDoc, PRUNE_T.csv, REP_U_ADDS.csv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]
2026-09-26 feat(hardware): C2 6L - finer router margin behind the exact check; 36 unrouted
    - router5 MARGIN configurable; repair runs with 0.025 mm (exact check in the
    loop guards the rules) -> USB-C CC2 escape and other tight pin exits open.
    - Altium DRC (state V): 0 short / clearance / width / component / antenna;
    36 unrouted (6 GND, 4 3V3_DIG, 2 3V0_ANA, 24 signals).
    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
    [EMG_MainBoard_Layout.PcbDoc, REG_USB_ADDS.csv, REG_USB_DELS.csv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]
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2026-09-26 feat(hardware): C2 6L - exact repair rounds Y/AC, plane-access mode; 24 unrouted
    - REP_Y (state Z): MCU ADC-corner region re-route + 2 passes; all four
    3V3_DIG links, ADC_EMG2, INA_OUT_3, MCU_SPI_MISO, WIFI_SPI_RDY closed.
    Its victim reconnects broke 10 other links in Altium (state AA 30):
    touch points were taken only at row ends, so T-junctions onto a
    track's middle were missed (2 antennae, pruned -> state AB).
    - repair.py: touch points now include every contact of other same-net
    copper along the group; REP_AC on AB then recovered them (+6) and the
    offline prediction matched Altium exactly (24).
    - router5.end_copper: prefer copper on the layer the DRC names
    (TP_3V3_DIG was mat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
    [DBG_3V3_ADDS.csv, DBG_3V3_DELS.csv, DBG_VB4_ADDS.csv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]
2026-09-26 feat(hardware): C2 6L - safe-margin retry in repair; 22 unrouted
    - repair.py: when a raster path fails the exact check (the raster can
    be one 0.05 mm cell optimistic at a copper edge), the same connection
    is re-routed at SAFE_MARGIN 0.06 before giving up (direct and after
    the victim rip). PLANE mode falls back to the partner-to-partner
    route when no plane via site exists.
    - REP_AE (state AC): FG_ALRT and the MCU 3V0_ANA trunk closed (+2),
    exact-clean, no deletions.
    - Altium DRC (state AF): 0 short / clearance / width / component,
    0 antennae; 22 unrouted (5 GND, 1 3V0_ANA, 16 signals).
    No fabrication approval (R2).
    Claude-S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
    [EMG_MainBoard_Layout.PcbDoc, REP_AD_ADDS.csv, REP_AD_DELS.csv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]
2026-09-26 feat(hardware): C2 6L - USB-C VBUS nudge (R_LIM, R_PGOOD); 21 unrouted
    Keep-rules / nudge-parts round.
    - R_LIM (17.05,37.54, 0) -> (18.90,37.55, 180) and R_PGOOD
    (17.60,42.35, 0) -> (18.85,42.40, 90), Bottom: both sat under the USB-C
    VBUS pins B4_A9 / A4_B9 and blocked their via-in-pad. Legal by
    place_part (3D bodies) and Altium DRC (0 component clearance); nets
    and BOM unchanged. Attached copper ripped first (rip_attached.py:
    only copper on the part's face or vias touching its pads).
    - REP_AI: all three VBUS links, NetR_LIM_2 and the R_PGOOD 3V3_DIG
    link routed (+5, exact-clean).
    - Side effect: new Top VBUS copper cut the L1 GND pour away from
    D_CC_ESD-3 (pour connectivity is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
    [EMG_MainBoard_Layout.PcbDoc, REP_AH_ADDS.csv, REP_AH_DELS.csv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]
2026-09-26 feat(hardware): C2 6L - victim clusters in repair; 19 unrouted
    - repair.py: ripped victims of one net whose copper touches are merged
    into one cluster (set_ends / touch_points_multi). The touch point
    between two ripped victims had no copper left, so every reconnect of
    such a pair failed ("victim-first ..." failures in REP_AH/AJ logs).
    - repair.py: every victim re-route is exact-checked; on failure it is
    retried at SAFE_MARGIN and then at the net's minimum width (route ends
    are forced free, so a wide track ending next to other copper broke
    clearance, e.g. BAT_TEMP vs the USB-C shield pad SH3).
    - REP_AJ (state AH): both VBAT_CELL links closed (+2), exact-clean.
    - Altium DRC (state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
    [EMG_MainBoard_Layout.PcbDoc, REP_AJ_ADDS.csv, REP_AJ_ADDS_OK.csv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]
2026-09-27 feat(hardware): C2 6L - region re-routes with reorder + plane-aware victims; 18 unrouted
    - repair.py region_pass: a rejected try is repeated with the lost groups
    routed before the targets (REORDER); a ripped GND / 3V0_ANA group only
    needs plane access per island (reconnect adds a via), no copper path.
    - REP_AM: channel-2 INA pin 3 (NetINA2_3) closed by a region re-route.
    - REP_AN: INA1-4 GND + DRL_LIMITED region, MCU bottom-left region,
    VOUT_2 and WIFI_SPI_CLK closed; Va_1 lost by an accepted region.
    - An antenna prune (prune_from_antennae) removed a live VOUT_2 chain
    (via contact missed); re-routed by REP_AN. Prunes are now always
    DRC-verified before use.
    - Pour side effects (not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
    [EMG_MainBoard_Layout.PcbDoc, REP_AM_ADDS.csv, REP_AM_ADDS_OK.csv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]
2026-09-27 feat(hardware): C2 6L - TP_VREF_B_SRC nudge frees U1 GND; 17 unrouted
    - Test pad TP_VREF_B_SRC (free Top pad, 1.0 mm) moved (12.50,20.20) ->
    (11.40,22.95): it sat over U1-11 (GND) and took the only legal plane
    via site next to it. Clearance-checked (chk_tp.py), attached Top
    copper ripped (rip_attached.py now accepts FREE:<pad>). Net unchanged.
    - REP_AO: U1 left-pin region re-routed (+2, no victim lost), one GND
    and one 3V0_ANA link closed directly (+4 total, exact-clean).
    - Altium DRC (state AN): 0 short / clearance / width / component,
    0 antennae; 17 unrouted (4 GND, 1 3V0_ANA, 12 signals).
    Cla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
    [EMG_MainBoard_Layout.PcbDoc, REP_AO_ADDS.csv, REP_AO_ADDS_OK.csv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]
2026-09-27 fix(hardware): C2 6L - JLCPCB standard-capability fixes + REP_AQ; 18 unrouted
    User asked (27 Sep) whether JLCPCB can build the minimum sizes. Checked
    against jlcpcb.com/capabilities/pcb-capabilities (multilayer, 1 oz):
    tracks 0.15 (JLC 0.09), gaps >= 0.13 (0.09), vias 0.45/0.2 = smallest
    normal-price via, via hole-to-hole 0.256 (0.2). Fixed the misses:
    - C_MCU_BULK (67.83,43.90) -> (67.55,43.60), rot 90: GND pad was 0.169 mm
    from the rounded board corner (JLC >= 0.2; now 0.5).
    - Via holes vs pad (PTH/NPTH) holes now >= 0.45 mm (JLC pad hole-to-hole):
    stitch vias next to both USB-C pegs and the MCU_SWCLK via next to the
    J_SWD Tag-Connect hole removed; geom.hole_gap / router pad-hole gro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
    [DELS_AO_FIX.csv, DELS_AQ_FIX.csv, DELS_SWCLK.csv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]
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2026-09-27 feat(hardware): C2 6L - repair round after C_BAT move; 11 unrouted, JLC clean
    - REP_AS (state AU): +10 - both C_BAT VBAT_CELL links, its GND,
    R_EN1_BIAS VSYS, C_MCU_BULK 3V3_DIG + GND, MCU_SWCLK (re-routed under
    the JLC pad-hole rule), DRL_SUM, VREF_B_SRC, one 3V0_ANA. Exact-clean,
    no deletions. Prediction matched Altium exactly.
    - Altium DRC (state AV): 0 short / clearance / width / component,
    0 antennae; 11 unrouted (2 GND, 1 3V0_ANA, 8 signals).
    - JLCPCB capability check (fab_check.py): copper to edge 0.500 mm,
    pad-hole to via-hole >= 0.483 mm, via-to-track >= 0.200 mm, track gap
    >= 0.130 mm, pad-to-track >= 0.153 mm - all within standard limits.
    No fabrication approval (R2).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
    [EMG_MainBoard_Layout.PcbDoc, REP_AS_ADDS.csv, REP_AS_ADDS_OK.csv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]
2026-09-27 feat(hardware): C2 - swap ADC_EMG5 from PA4 to PC4 (same ADC1)
    User request (27 Sep): swap MCU ADC pins where it helps routing.
    - ADC_EMG5 moves from U_MCU1 pin 29 (PA4, ADC1_IN9) to pin 33 (PC4,
    ADC1_IN13). Both are ADC1 (14-bit) per STM32U575 datasheet DS13737
    Table 26, so the 5-channel ADC1 scan is unchanged except the channel
    number (firmware scan list: IN5, IN6, IN7, IN8, IN13).
    - Schematic MCU_sheet.SchDoc: the ADC_EMG5 stub wire + net label moved
    from PA4 to PC4, PC4's no-ERC marker moved to PA4 (pinswap_T.pas; each
    object matched by exact location; read back).
    - PCB: pad U_MCU1.33 = ADC_EMG5, pad U_MCU1.29 = no net (no copper was
    attached to pin 29) - schematic and PCB st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
    [ADC5_PC4_PLAN.csv, EMG_MainBoard_Layout.PcbDoc, MCU_sheet.SchDoc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]
2026-09-27 feat(hardware): C2 - Wi-Fi UART to PB6/PB7 (USART1), ADC_EMG5 routed
    User-approved pin swap (27 Sep): "if those pins will not use and they are
    the extra one with same configuration" - verified first:
    - LQFP100 pins 92/93 (PB6/PB7) are unconnected in the PCB and carry no-ERC
    markers in the schematic; per STM32U575 DS13737 Table 26 they are
    USART1_TX / USART1_RX (AF7), the same peripheral as PA9/PA10 (68/69),
    all FT I/O -> identical function, only the pin mux changes.
    - Schematic MCU_sheet.SchDoc (uartswap_T.pas, objects matched by exact
    location): the PA9/PA10 wire segments removed (the link resistors keep
    their MCU_WIFI_UART_TX/RX labels), PB6/PB7 no-ERC markers moved to
    PA9/PA10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
    [EMG_MainBoard_Layout.PcbDoc, MCU_sheet.SchDoc, REP_AU_ADDS.csv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]
2026-09-27 feat(hardware): C2 6L - state AZ (9 unrouted), negotiated router, handoff to Astra
    State AZ written in Altium (saved, DRC: copper clean, 9 unrouted; 1 dead VREF_A
    stub antenna): AY + MERGE_G = REP_CB3 (VOUT_2) + REP_DA4 (GND C_DRL_DEC-2).
    Ready but NOT yet written: MERGE_I_ADDS_OK / MERGE_I_DELS_OK (183 add / 134 del,
    exact check 0 problems) = NetLED_CHG_C (REP_FC3) + GND CU_14-1 (REP_FA) +
    3V0_ANA U1-4 (NEG_C9) + prune of the dead VREF_A stub -> 6 unrouted after write.
    Repair tool upgrades (work/repair.py, router5.py, run_repair.py), all env-gated:
    - ONLY_BOX, DIAG_FIXED (route vs fixed copper only -> blockers or "needs a
    placement/pin change"), GUIDED victims, CASCADE / reverse cascade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
    [DBG_CC2_ADDS.csv, DBG_CC2_DELS.csv, DBG_CC_ADDS.csv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]
2026-09-27 feat(hardware): C2 6L - all connections routed (state BJ, 0 unrouted)
    Astra's continuation of the C2 6-layer routing (from handoff 39b95e4), saved
    state BJ; Claude independently re-verified it before this commit:
    - PcbDoc SHA256 0acc1e8e...585c = the file Astra checked.
    - Altium DRC_C2_6L_BJ (re-parsed): 0 unrouted, 0 short / clearance / width,
    0 net antennae; 246 findings left, all overlay: 157 silk-to-mask,
    84 silk-to-silk, 5 board outline (overlay text/graphics).
    - fab_check (JLC standard): min trace 0.15, gap 0.13, via 0.45/0.2 |
    0.5/0.3 | 0.6/0.3, via-track 0.200, via hole-hole 0.256, pad hole-hole
    0.483, edge 0.50 -> within JLC standard limits.
    - clearance_scan / clearance_diff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
    [AFE_Channel_1.SchDoc, AFE_Channel_2.SchDoc, AFE_Channel_3.SchDoc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]

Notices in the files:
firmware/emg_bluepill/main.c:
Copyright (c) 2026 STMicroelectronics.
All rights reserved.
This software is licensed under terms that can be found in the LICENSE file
